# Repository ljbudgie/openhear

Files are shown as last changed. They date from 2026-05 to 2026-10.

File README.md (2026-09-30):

<p align="center">
  OpenHear hero
</p>

# OpenHear

**First time here?** Start at <a href="START_HERE.md">START_HERE.md</a> — phone, audiogram, ten minutes. You do not need GitHub after that.

### Your senses. Your data. Your world.



**Built on the Burgess Principle** — see [docs/BURGESS_PRINCIPLE.md](docs/BURGESS_PRINCIPLE.md).
→ <a href="docs/index.md">Full documentation index</a>

> **⚠️ EXPERIMENTAL — NOT A MEDICAL DEVICE**
> OpenHear is a research platform and public build log, not a certified hearing aid.
> Start at low volume, validate every configuration on your own hardware, and do
> not treat any module in this repository as a substitute for clinical care.

OpenHear is a human sensory sovereignty platform — not a hearing aid, not a wellness device, not a consumer gadget. It is an open-source sovereign audio pipeline, haptic environment engine, therapeutic delivery layer, and future aids-free sensory system.

**North star: human sensory sovereignty.** The user decides what they hear, when they hear it, how they hear it, and what their acoustic environment does to their body and mind. The long-term configuration is still direct: no hearing aid, no behind-the-ear receiver, no bone conduction implant, no ear canal device of any kind. The wristband IS the hearing system. See **[Vision — Aids-Free Hearing](#openhear-vision-2--aids-free-hearing-the-wristband-is-the-hearing-system)** below, the full eight-pillar platform architecture in [`docs/HUMAN_SENSORY_SOVEREIGNTY_ARCHITECTURE.md`](docs/HUMAN_SENSORY_SOVEREIGNTY_ARCHITECTURE.md), and the aids-free subsystem document in [`docs/AIDS_FREE_ARCHITECTURE.md`](docs/AIDS_FREE_ARCHITECTURE.md).

> *The hearing aid industry charges £3,000–£8,000 for hardware, then locks you out of it.*
> *Your audiogram is a measurement of your body. It belongs to you.*
> *OpenHear gives it back.*

---

## Contents

- <a href="START_HERE.md">Start here</a>
- [Why OpenHear in 2026](#why-openhear-in-2026)
- [What this is](#what-this-is)
- [The Burgess Principle](#the-burgess-principle)
- [The problem](#the-problem)
- [What OpenHear does](#what-openhear-does)
- [OpenHear Wristband — Active Environmental Intelligence](#openhear-wristband--active-environmental-intelligence)
- [OpenHear Vision — The Wristband as the Hearing System](#openhear-vision--the-wristband-as-the-hearing-system)
- [OpenHear Vision 2 — Aids-Free Hearing](#openhear-vision-2--aids-free-hearing-the-wristband-is-the-hearing-system)
- [Getting started — three paths](#getting-started--three-paths)
- [Roadmap](#roadmap)
- [Nine pillars](#openhear-expansion--nine-pillars)
- [Sovereign philosophy](#sovereign-philosophy--enforced-at-every-layer)
- [Contributing](#contributing)
- [Legal](#legal)
- [Author](#author)

---

## Why OpenHear in 2026

Commercial aids from Phonak, Signia, and Starkey still ship with proprietary AI that mangles your own voice, whistles during hugs, and dies in sweat. Replacements cost £3,000–£8,000 and lock you into manufacturer fitting software. OpenHear is the sovereign alternative: an open-source DSP pipeline with adaptive feedback cancellation, own-voice bypass, and sweat-proof 3D-printed ITE shells you manufacture at home. Every algorithm is inspectable. Every parameter is yours. No cloud. No subscription. No lock-in. Licensed under Apache 2.0 with a Sovereign Use Addendum (see [`LICENSE`](LICENSE)).

---

## What this is

OpenHear is an open-source human sensory sovereignty platform for people who are tired of factory AI, clinic gatekeeping, and environmental noise making decisions about their own senses without their consent.

It already works with aids you own and hardware you have. It is being extended into a wrist-native sensory system, a therapeutic haptic platform, a selective-hearing engine, and an acoustic privacy layer. It does not require an audiologist appointment to change a setting.

OpenHear is now both a software pipeline and a hardware concept. The pipeline gives you control over how your aids process sound. The hardware — the OpenHear Wristband (in development) — extends that control outwards into the environment itself, scanning for sounds your aids may not pick up and translating them into haptic awareness on the wrist. Software and hardware are unified by a single principle: the hearing aid user should have full sovereignty over how they perceive their acoustic environment.

OpenHear has nine pillars:

1. The OpenHear Wristband — active environmental intelligence
2. Aids-free architecture — the wristband as the complete hearing system
3. Peak hearing for all users
4. Selective acoustic sovereignty
5. Therapeutic frequency delivery
6. Native iOS and Android integration
7. Emotional and cognitive acoustic intelligence
8. Social acoustic layer
9. Beyond biological hearing

### New north-star documents

- Full architecture — [`docs/HUMAN_SENSORY_SOVEREIGNTY_ARCHITECTURE.md`](docs/HUMAN_SENSORY_SOVEREIGNTY_ARCHITECTURE.md)
- Aids-free subsystem architecture — [`docs/AIDS_FREE_ARCHITECTURE.md`](docs/AIDS_FREE_ARCHITECTURE.md)
- Research roadmap — [`docs/RESEARCH_ROADMAP.md`](docs/RESEARCH_ROADMAP.md)
- Immediate engagement list — [`docs/PRIOR_ART.md`](docs/PRIOR_ART.md)
- Go-to-market, mission, and showcase applications — [`docs/GO_TO_MARKET.md`](docs/GO_TO_MARKET.md)
- Funding and partnerships — [`docs/FUNDING_AND_PARTNERSHIPS.md`](docs/FUNDING_AND_PARTNERSHIPS.md)
- Regeneration vision and roadmap — [`REGEN_VISION.md`](REGEN_VISION.md)
- Superior-hearing roadmap (functionally exceed natural hearing) — [`SUPERIOR_HEARING_ROADMAP.md`](SUPERIOR_HEARING_ROADMAP.md)

### Mission

OpenHear gives people control over their own senses. It lets you choose what you hear, what you ignore, what your body learns from sound, and how your environment reaches you, whether you are deaf, hard of hearing, hearing, tired, stressed, training, sleeping, working, or simply wanting peace.

**Tested on:**
- Phonak Naída M70-SP (Marvel platform)
- Signia Insio 7AX (Augmented Xperience platform)

**Required hardware:**

Path 1 does not need this hardware. See START_HERE.md. Noahlink is only Path 2 (people who already own compatible aids and want to read their own fitting).

- Noahlink Wireless 2 (~£80 on eBay)
- Windows laptop (for fitting software)
- iPhone or Android (for streaming)
- OpenHear Wristband *(in development)* — continuous-wear haptic frequency scanner, pairs over Bluetooth with the rest of the pipeline. See the OpenHear Wristband section below.

---

## The Burgess Principle

The Burgess Principle is the ethical and architectural root from which OpenHear grows. It is a framework, authored by Lewis James Burgess, for sovereign handling of clinical audiology data — audiograms, fittings, MPO calculations — so that a patient, a clinician, and a regulator can each hold an independent, verifiable, offline record of what was committed to and by whom, without depending on the cooperation of any vendor.

It rests on five commitments, enforced in this repository (see `advocacy/gate.py`, `advocacy/adapters.py`, and `NOTICE`):

1. **Sovereign facts belong to the person they describe.** The audiogram and fitting profile are facts about a human body and are never transmitted, bundled, or shared without that person's explicit, informed consent.
2. **Every clinical commitment is cryptographically verifiable.** A SHA-256 commitment over a canonical serialisation of the facts is the only value intended to leave the device, and any party holding the bundle can verify it offline with no vendor involvement.
3. **Trust is binary: `SOVEREIGN` or `NULL`.** A real human personally reviewing the specific facts and signing a receipt produces `SOVEREIGN`; pure automation, blanket policy, an invalid signature, tampering, or a refusal to engage produces `NULL`. There is no third state.
4. **Raw audio is not a clinical fact.** Any attempt to commit `bytes`, `bytearray`, `memoryview`, or a NumPy `ndarray` into a facts payload raises `RawAudioRejectedError` before a commitment is produced.
5. **Schema ownership is singular.** The `openhear-advocacy-v1` schema family is owned by this repository; integrators do not fork, re-version, or extend it.

The advocacy layer in this repository is the reference implementation of these commitments. The next layer — **Iris**, an AI companion built within the Burgess Principle — will provide a higher-level advocacy workflow post-1.0.0. Iris will import OpenHear; OpenHear will not import Iris. An integration that satisfies the five commitments today will be compatible with Iris automatically.

The full statement of the principle, the integrator contract, and the runnable reference integration are in [`docs/BURGESS_PRINCIPLE.md`](docs/BURGESS_PRINCIPLE.md), [`docs/ADVOCACY_INTEGRATION.md`](docs/ADVOCACY_INTEGRATION.md), [`docs/INTEGRATORS.md`](docs/INTEGRATORS.md), and [`examples/reference_integration.py`](examples/reference_integration.py).

---

## The problem

Modern hearing aids are extraordinary pieces of engineering. They are also, deliberately, black boxes.

When you buy a Phonak or Signia aid, you get a device that:
- Constantly reclassifies your acoustic environment without telling you
- Applies compression, noise reduction, and beamforming algorithms you cannot inspect
- Stores your audiogram and fitting profile in a proprietary format you cannot read
- Requires a registered audiologist and £200+/hr of fitting time to adjust a single parameter
- Reverts to factory defaults if the fitting software version doesn't match

This is not a safety requirement. It is a business model.

The audiogram stored in your hearing aids is a biometric measurement of your nervous system. The fitting profile is a record of how your brain processes sound. You generated that data. You wore the sensors. You sat in the booth.

It is yours.

---

## What OpenHear does
```
World → Microphone → Custom DSP Engine → Bluetooth Stream → Your Aids → Your Ears
```

**Core module** — reads your existing fitting data out of your aids via Noahlink Wireless. Exposes it as plain JSON. No proprietary format, no locked PDF.

**DSP module** — real-time Python audio pipeline. You control the compression curve, the noise floor, the beamforming angle, the voice frequency emphasis. Tuned to your audiogram, not a population average.

**Stream module** — sends processed audio directly to your aids over Bluetooth. No extra hardware. Works on iPhone and Android.

**Audiogram module** — reads, visualises, and exports your hearing thresholds in open formats. The data your audiologist has been keeping in a system you can't access.

**Learn module** *(Phase 6)* — a local preference engine that adjusts to your own corrections over time. Listener A/B choices are captured by [`learn/preferences.py`](learn/preferences.py), folded into deterministic config suggestions by [`learn/engine.py`](learn/engine.py), and recalled per environment via the saved profiles in [`learn/profiles.py`](learn/profiles.py). Your hearing profile improves every day, not once every two years.

---

## OpenHear Wristband — Active Environmental Intelligence

The pipeline above improves the sound that already reaches your aids. The wristband does something different: it scans the environment in parallel, on the wrist, and tells you about sounds your aids never delivered — or sounds you weren't oriented toward.

It is a continuous-wear device designed to work *alongside* hearing aids, not replace them. Passive amplification becomes active environmental intelligence.

```
World → Wrist Microphone Array → On-device AI Classifier → Haptic Motor Array → Your Wrist
                                          ↕
                                     Bluetooth
                                          ↕
                                Aids · Phone · Pipeline
```

**Edge AI sound classification** — low-latency on-device inference identifies environmental sounds in real time. Nothing is sent to a cloud. Your environment is your data and it stays on the wrist. The same sovereignty principle that governs your audiogram governs every sample the wristband hears.

**Multi-motor haptic feedback** — an array of small motors arranged around the wrist creates a spatial sound field through haptic patterns. Different sound classes, directions, and frequency bands have distinct haptic signatures. You build a physical sense of your acoustic surroundings without relying solely on what your aids decide to amplify.

**Directional awareness through haptic mapping** — the wristband communicates not just *what* a sound is but *where* it is coming from. Motor positions map to compass points around the wrist, so a siren behind you, a voice to your left, and a doorbell in front feel distinctly different. This is spatial awareness for sounds the aids may not be picking up or that you simply aren't oriented toward.

**Bluetooth connectivity** — pairs with hearing aids, smartphones, and smart home systems. Speaks the same protocols as the rest of the OpenHear pipeline so the wristband, the aids, and the DSP module act as one unified system rather than three separate devices.

**Personalised AI models** — the classifier adapts to the user's specific environment over time. A user in a barbershop has different priority sounds to a user in an office; the model learns the difference and adjusts haptic responses accordingly, with no manual configuration. Adaptation happens locally on the device.

**Proactive frequency-specific scanning** — instead of reacting after a sound has occurred, the wristband actively scans the frequency spectrum and alerts you to sounds approaching your detection threshold *before* they become relevant. Environmental sonar, not environmental amplification.

### How it relates to existing devices

The collaboration enquiry that prompted this work came from Sharp Hearing, a UK audiology clinic that already features the [Neosensory Buzz](https://neosensory.com/) on their site — a basic haptic wristband that converts sound into vibration patterns. The OpenHear Wristband goes significantly further:

| Capability | Neosensory Buzz | OpenHear Wristband |
|---|---|---|
| Sound → vibration | ✓ | ✓ |
| On-device AI sound classification | — | ✓ |
| Directional haptic mapping (compass points on the wrist) | — | ✓ |
| Proactive frequency-specific scanning | — | ✓ |
| Personalised models that adapt to your environment | — | ✓ |
| Pairs into a sovereign open-source DSP pipeline | — | ✓ |
| Local-only — no cloud, no telemetry | partial | ✓ |

### Why this fits OpenHear

The developer wears Phonak Naída and Signia aids. The gap the wristband fills is one lived every day: aids amplify what reaches the microphones in front of your ears, in the direction you happen to be facing, within the frequency response the manufacturer chose. Everything outside that envelope is silence. The wristband closes that gap on the wrist, under the user's control, with the same data-sovereignty guarantees as the rest of the project.

---

## OpenHear Vision — The Wristband as the Hearing System

The wristband section above describes a companion device. This section describes where the architecture is going.

The long-term vision is direct: the wristband stops being a companion and becomes the hearing system. It captures the environment, classifies it, processes it against your audiogram, and transmits a finished audio signal to a minimal receiver worn at the ear. The £3,000–£8,000 behind-the-ear black box — with its proprietary firmware, locked fitting software, and audiologist-gated parameters — is no longer required. It is replaced by a piece of jewellery on the wrist and a passive driver at the ear.

### The architecture — three layers, one user

```
World → Wrist Mic Array + Hearing NPU → Wireless Link → Bone Conduction Receiver / Open-Fit Earbud → Cochlea
        [capture + classify + process]   [low-latency]   [deliver only]
```

**Layer 1 — Wrist (sensor and processor).** The wristband carries the microphone array, the hearing-specific neural processing unit, the audiogram, and the DSP pipeline. All of the intelligence of the system lives here, on the user's wrist, where it can be charged, updated, inspected, and replaced independently of anything worn at the ear.

**Layer 2 — Wireless transmission.** A low-latency link between the wrist and the ear-worn receiver. Sub-5ms end-to-end is the target. Standard, open, and inspectable — no proprietary radio that locks the receiver to a single vendor.

**Layer 3 — Ear (delivery only).** A minimal behind-the-ear bone conduction receiver, or an open-fit earbud, whose only job is to convert the finished signal into vibration or sound. No microphones. No classifier. No DSP. No firmware that does anything other than receive and drive a transducer. When it breaks, you replace a £30 part, not a £6,000 one.

### A hearing-specific NPU — designed for this and only this

The processor on the wrist is not a general-purpose AI chip with a hearing application bolted on top. It is a neural processing unit designed from first principles for one task: real-time, personalised hearing.

- **Sub-5ms end-to-end latency** — capture to ear. Anything slower is felt as delay during conversation.
- **Personalised audiogram-based DSP** — compression curves, frequency shaping, and feedback cancellation derived from *your* thresholds, not a population fit.
- **On-device classification and beamforming** — environmental scene analysis and spatial steering run locally, at the same latency budget as the DSP itself.
- **Performance targets that exceed current hearing aid SoCs** — at a fraction of the silicon cost, because the chip does one job extremely well rather than every job adequately.

A general-purpose chip repurposed for hearing will always lose to a chip that was drawn for hearing. We intend to draw the chip.

### Sovereignty extended to hardware

OpenHear already gives the user sovereignty over their audiogram, their fitting data, and the DSP algorithms that act on them. The wristband-as-hearing-system extends that sovereignty down to the silicon and out to every device worn on the body.

- **No proprietary firmware** at any layer of the stack — wrist, link, or receiver.
- **No locked fitting software.** The audiogram lives on the wrist as plain JSON. Adjusting a parameter means editing a value, not booking an appointment.
- **No audiologist gatekeeping.** Audiologists are welcome as collaborators and clinicians; they are not required as a key to your own hearing.
- **No vendor lock between layers.** The receiver at the ear is interchangeable. The wristband is interchangeable. The link is an open standard. The user owns every layer.

The hearing aid industry's business model depends on the user not being able to see inside the device. This architecture is the device with the lid removed.

### Regulatory pathway

The system enters the world as a **companion device** — running alongside existing hearing aids, augmenting them, doing nothing the aids themselves do. This is the position the current OpenHear pipeline and wristband already occupy and it requires no clinical claim to be made.

The standalone configuration — wristband plus bone conduction receiver, replacing the hearing aid entirely — is the longer pathway. The regulatory target for the standalone device in the United Kingdom is **UK MDR 2002 Class IIa**, the same classification carried by conventional air-conduction hearing aids. Clinical evidence accumulates first; the claim follows.

### Collaboration

Open source hardware and open source software, end to end. Schematics, RTL, firmware, DSP, and fitting tools all under permissive licenses. Specifically invited:

- **Audiologists** — clinical input on fitting protocols, validation, and the standalone regulatory pathway.
- **Chip designers** — architects and RTL engineers interested in a hearing-specific NPU built from first principles.
- **DSP engineers** — compression, beamforming, feedback cancellation, and own-voice detection at sub-5ms latency budgets.
- **Hearing aid users** — the people the system exists for. Lived experience is a design input, not a marketing line.

### Industry & Institutional Engagement

**Industry engagement (active, July–August 2026)**

Commercial integration conversations are active with multiple wellness technology and assistive device companies. The discussions cover acoustic environment classification, haptic rendering, and the governance wrapper.

The commercial model is COSS (Commercial Open Source Software): the open core (Apache 2.0) is permanently free; the governance layer (UK Certification Mark UK00004343685) is licensed commercially per device at scale. A formal term sheet for a two-phase integration partnership — Phase 1 technical evaluation, Phase 2 paid integration pilot — has been prepared and is in circulation.

Sharp Hearing (US audiology clinic) is recorded as the first formal industry contact, 20 April 2026.

**Institutional partnerships (active)**

- **Health Innovation North East and North Cumbria (HI NENC)**, funded by the UK Office of Life Sciences — Innovation Pathway ref 1643. A market analyst is conducting competitive landscape research across seven sections: competitor analysis, NHS landscape, regulatory pathway, patent/prior art, market sizing, pricing, and evidence base.
- **RNID (Royal National Institute for Deaf People)** — confirmed participant recruitment from the Research Panel (~1,600 members, ~1,100 hearing aid users) launching 12 August 2026. Innovation Seed Fund application planned November 2026.
- **UK Information Commissioner's Office** — IC-501417-W5W9: the ICO found Sonova/Phonak's response to a Subject Access Request regarding AutoSense OS algorithmic accountability inadequate (outcome letter 31 July 2026) and is writing to Sonova directly.
- **MHRA** — CEC 253215: medical device safety concern regarding AutoSense OS automated clinical decision-making; FOI2026/00527 internal review requested regarding DSAR reclassification and substantive regulatory questions.

**Regulatory and academic record**

- UK Certification Mark UK00004343685 accepted 21 July 2026, published in Trade Marks Journal 24 July 2026, opposition period to 24 September 2026.
- 7 papers publicly distributed on SSRN (author page: per\_id=11571908); lead paper: The Burgess Test v2.1 (SSRN 6759778).
- 100 classified findings across 12 sectors: 78 NULL, 8 SOVEREIGN, 10 AMBIGUOUS, 4 confirmed resolutions.
- First judicial validation: TPT DK00003-2605 ALLOWED, 14 June 2026.

**Accessibility profiles (v1.4.0+)**

Optional, user-declared accessibility profiles are shipped for cerebral palsy, autism, and sensory-processing needs. In the live wristband path they damp non-safety haptics, configure a firmware-enforced gradual onset, raise the confidence gate, and widen alert spacing; cerebral palsy also supplies hold-to-confirm and dysarthria-tolerant voice defaults. Alarm delivery remains subject to its perceptibility floor. Nothing is detected, inferred, stored, or transmitted. See [`accessibility/README.md`](accessibility/README.md).

---

## OpenHear Vision 2 — Aids-Free Hearing: the wristband IS the hearing system

The previous section described removing the £3,000–£8,000 behind-the-ear processor and keeping only a minimal ear-worn receiver. This section goes one further. **It removes the receiver too.**

There is no hearing aid in this system.
There is no behind-the-ear receiver.
There is no bone conduction implant.
There is no ear canal device of any kind.

There is a wristband, a personal model, an audiogram, and a brain trained to read them. The user owns all four.

The full eight-pillar platform architecture is in [`docs/HUMAN_SENSORY_SOVEREIGNTY_ARCHITECTURE.md`](docs/HUMAN_SENSORY_SOVEREIGNTY_ARCHITECTURE.md). The aids-free subsystem architecture is in [`docs/AIDS_FREE_ARCHITECTURE.md`](docs/AIDS_FREE_ARCHITECTURE.md). The 15 most critical open research questions are in [`docs/RESEARCH_ROADMAP.md`](docs/RESEARCH_ROADMAP.md). The immediate engagement list is in [`docs/PRIOR_ART.md`](docs/PRIOR_ART.md). The audience positioning, mission, and showcase applications are in [`docs/GO_TO_MARKET.md`](docs/GO_TO_MARKET.md). The funding and partnership strategy is in [`docs/FUNDING_AND_PARTNERSHIPS.md`](docs/FUNDING_AND_PARTNERSHIPS.md). What follows is the short version.

### Mechanism of action — sensory substitution, not amplification

OpenHear's standalone configuration is not a hearing aid by mechanism. It is a **somatosensory hearing substitution device**. Sound is captured at the wrist, classified by edge AI, weighted against the user's audiogram, and rendered as a high-resolution multi-frequency haptic field on the skin. The brain — through documented neuroplasticity, going back to Bach-y-Rita's 1969 tactile-vision substitution work — learns to read that field as auditory information.

This is the same class of device as the Neosensory Buzz, but with an order of magnitude more channels, true frequency-rich spatial encoding, audiogram-weighted band synthesis, and an open silicon and open RTL stack. It is not a hearing aid. It does not claim to restore cochlear function. It substitutes for it.

### Skin as the transducer

The volar wrist carries Pacinian, Meissner, Merkel and Ruffini mechanoreceptors covering roughly 5 Hz – 1 kHz of perceivable mechanical drive. Audio above this band is *encoded* — into motor position, drive pattern, and temporal structure across the array — not transmitted as raw vibration. Target actuator pitch is 8–12 mm, deliberately tighter than two-point discrimination, exploiting funnelling and apparent-motion illusions to produce a perceived spatial resolution finer than the physical receptor field.

- **Minimum viable**: 24 actuators in a single ring (Neosensory-class density).
- **Target v1**: 64 actuators in a 4-ring × 16-column lattice covering the wrist.
- **Aspirational v2**: 128 actuators extending up the forearm, enabling a 2D haptic "screen".

### Neural adaptation — open protocol, user-owned data

Adaptation is the design target, not raw signal fidelity. The training pipeline is published as a five-phase open protocol — calibration, phoneme sandbox, words and environment, open conversation, spatial and extended-spectrum — running on a cross-platform companion app. All data lives on the user's device as plain Parquet. There is no cloud account.

```
Phase 0  Calibration         (day 0,    ~90 min)   — perceptual mapping, motor thresholds, audiogram import
Phase 1  Phoneme sandbox     (week 1–2, 30 min/d)  — closed-set phoneme → haptic pattern drills
Phase 2  Word & environment  (week 3–6, 30 min/d)  — common words, alarms, name detection, traffic
Phase 3  Open conversation   (week 7+,  passive)   — continuous wear; periodic active-recall checks
Phase 4  Spatial & extended  (month 3+)            — direction, elevation, ultrasonic/infrasonic bands
```

Phase 2 has a local-only scaffold for word, name, and environment training:

```bash
python -m stream.phase2_training list
python -m stream.phase2_training run --target word_water --scores word_water=0.92 --progress /tmp/openhear-phase2-progress.json
python -m stream.phase2_training summary --progress /tmp/openhear-phase2-progress.json
```

The Phase 2 progress file stores only target ids, classifier labels, scores,
timing, and outcomes. It does not store raw audio or speaker identity.

Phase 3 has a local-only scaffold for open conversation telemetry:

```bash
python -m stream.phase3_open_conversation list-prompts
python -m stream.phase3_open_conversation passive   --sound-class voice --source-label Speech --confidence 0.9   --intensity 128 --progress /tmp/openhear-phase3-progress.json
python -m stream.phase3_open_conversation summary   --progress /tmp/openhear-phase3-progress.json
```

The Phase 3 progress file stores only derived metadata for passive wear and
active-recall checks. It does not store raw audio, waveforms, speaker identity,
or cloud identifiers, and it is experimental telemetry rather than clinical
evidence.

Phase 4 adds a local-only scaffold for spatial and extended-band training:

```bash
python -m stream.phase4_spatial_extended list-tasks
python -m stream.phase4_spatial_extended spatial --task localise_left --predicted-azimuth -80 --confidence 0.85 --user-response answered --progress /tmp/openhear-phase4-progress.json
python -m stream.phase4_spatial_extended extended --task band_ultrasonic --predicted-band ultrasonic --user-response ultrasonic --progress /tmp/openhear-phase4-progress.json
python -m stream.phase4_spatial_extended summary --progress /tmp/openhear-phase4-progress.json
```

The Phase 4 progress file stores only derived localisation, extended-band,
timing, environment, rating, and outcome metadata. It does not store raw audio,
waveforms, location traces, biometric identifiers, cloud identifiers, or
clinical claims.

### Phase 5 — Sovereign Device bundle

Phase 5 is the local, one-click bridge from an audiogram to a self-contained
device build. It generates firmware plus a sovereign build manifest from a
`openhear-audiogram-v1` JSON file, with no network dependency and no raw audio:

```bash
python -m hardware.sovereign_device.pipeline AUDIOGRAM.json ./build --ear right
```

The manifest records firmware, audiogram, and component-database hashes,
safety requirements, regulatory status, and cost-target status without
embedding the underlying audiogram thresholds. Full plan and exit criteria
are in [`docs/PHASE5_SOVEREIGN_DEVICE.md`](docs/PHASE5_SOVEREIGN_DEVICE.md).

### A Hearing NPU, designed from first principles

A general-purpose mobile SoC running PyTorch Mobile cannot meet the latency or power budget. The Hearing NPU is designed for *one* job: continuous, personalised, low-latency hearing-as-haptics.

| Stage | Latency budget |
|---|---|
| Mic capture + ADC | 0.3 ms |
| Front-end DSP (beamform, AEC, VAD) | 0.7 ms |
| Bark-band analysis (FFT/filterbank)| 0.5 ms |
| Audiogram weighting | 0.1 ms |
| Classification + scene tag | 1.5 ms |
| Haptic render (mapping + envelope) | 0.6 ms |
| Motor driver chain | 0.8 ms |
| Mechanical rise time (LRA/piezo) | 0.5 ms |
| **End-to-end target** | **≤ 5 ms**|

- **ISA**: RISC-V RV32IMC + RVV 1.0 (open ISA, open implementations).
- **Accelerator**: 8 × INT8/INT4 MAC tiles at ~2 TOPS, hardwired bark filterbank, single-cycle audiogram lookup, deterministic haptic scheduler.
- **SRAM-only data path**: 4 MB on-die, no DRAM. The model lives entirely on chip; this is the architectural reason ≤ 5 ms is achievable.
- **Power envelope**: 80–120 mW continuous, < 5 mW idle.
- **Open RTL** under CERN-OHL-S. No proprietary IP in the data path.

Until tape-out, the staged hardware path is: v0 on Raspberry Pi CM4 + Hailo-8L (~30 ms latency, sufficient for adaptation studies) → v0.5 on a RISC-V SBC + Coral Edge TPU (~15 ms) → v1 FPGA validation on Lattice ECP5 with the open RTL (~5 ms) → v1 ASIC at 22 nm FD-SOI.

### Beyond hearing — capabilities a hearing aid cannot have

Once sound is decoupled from the ear and rendered as multi-channel haptics, the system trivially extends past biological limits.

- **Infrasonic** (1–20 Hz) — earthquake precursors, large-vehicle approach, HVAC faults.
- **Ultrasonic** (20–96 kHz with appropriate MEMS) — bat activity, leak detection, dog whistles.
- **Full-sphere spatial awareness** — azimuth via beamformer, elevation via ring index, distance via envelope decay. Above and below the wearer, which biological hearing handles poorly.
- **Multi-source separation** — render two simultaneous speakers to two distinct regions of the wrist, allowing the wearer to "listen" to both in parallel.
- **Persistent acoustic memory** — last 30 s ring buffer, replayable on demand to the haptic field.
- **Contextual silencing** — known irritant classes attenuated by the classifier, not by global compression.

Biological hearing is a 20 Hz – 20 kHz omnidirectional pressure sensor with poor elevation discrimination and no scene understanding. OpenHear, on the wrist, is none of those things and all of the things they cannot be. The aids-free configuration is **superior, not equivalent**.

### Sovereignty enforced at the technical layer

The user owns:

1. **Audiogram** — `~/.openhear/audiogram.json`
2. **Haptic preference profile** — `~/.openhear/profile.json`
3. **Personal adaptation model** — `~/.openhear/model.bin` (LoRA delta over the open base)
4. **Adaptation telemetry** — `~/.openhear/training/*.parquet`
5. **Any captured audio** — opt-in only, encrypted with a key the user holds.

Enforcement is not a policy promise; it is built in:

- The NPU has no IP stack. There is no network egress in the hearing data path.
- Firmware is signed, but the signing key is the user's. A user can sign and load their own firmware. (This is the inverse of the hearing aid industry's lock-down.)
- Plain-file formats end to end — JSON, Parquet, ONNX, WAV. No proprietary container.
- Every parameter an audiologist would set in proprietary fitting software is a writable field in `profile.json`. Audiologists are welcome collaborators; they are not a key.

### Regulatory pathway — sensory substitution, not hearing aid

Regulatory classification follows mechanism, not indication. The aids-free OpenHear has the same mechanism as Neosensory Buzz and BrainPort, both of which are cleared as sensory substitution devices, not hearing aids.

| Jurisdiction | Likely classification | Comparator predicate |
|---|---|---|
| **UK (MHRA)** | UK MDR 2002 — Class I (initial), Class IIa if claims tighten | Neosensory Buzz |
| **US (FDA)**  | 510(k) Class II, sensory substitution | Neosensory Buzz, BrainPort Vision Pro |
| **EU (MDR)**  | Class I or IIa under MDR 2017/745 | Same |

The fastest credible path: bench validation in months → single-user adaptation log (publicly, by the developer) → multi-user pilot (n≈20) in year 1 → controlled trial in year 2 → submission in year 3. Open data at every stage.

### Open hardware path

- Schematics: KiCad 8 wristband package planned for a future `hardware/wristband/` directory; not yet committed in this repo.
- RTL: Verilog/SystemVerilog Hearing NPU package planned for a future `hardware/npu/` directory; not yet committed in this repo.
- Mechanical: FreeCAD/OpenSCAD wristband CAD planned for a future `hardware/wristband/mech/` directory; not yet committed in this repo.
- BOM: globally-available distributors only; no single-source critical parts.
- Targeting OSHWA certification at v0 and a Hackaday Prize / Open Hardware Summit submission.

### Specifically invited

- **Mechanoreceptive psychophysicists** — for Q1 (information bandwidth of the wrist) and Q4 (calibration protocol) of the [research roadmap](docs/RESEARCH_ROADMAP.md).
- **Sensory-substitution neuroscientists** — for Q2 (adaptation timeline) and the cortical remap evidence base.
- **RISC-V RTL engineers** — for the Hearing NPU.
- **Embedded DSP engineers** — for the sub-5 ms front-end and haptic renderer.
- **UK / EU / US audiology clinicians** — for the multi-user pilot and the regulatory pre-submissions.
- **Deaf and hard-of-hearing wearers** — the people the system exists for. Lived experience is a design input, not a marketing line.

The longer this section gets, the closer the architecture is to leaving the page. The architecture document and roadmap are both in this repo. Read them; fork them; contradict them; submit a PR.

---

## The three pain points this solves

| Problem | Factory behaviour | OpenHear behaviour |
|---|---|---|
| Voices sound unnatural | AutoSense OS reclassifies constantly, smears transients | Linear mode + tunable WDRC compression |
| Constant unwanted adjustments | Environment AI fires every few seconds | You are the AI |
| Too much background noise | Fixed factory noise floor | Tunable beamforming, adjustable noise gate |

---

## Philosophical foundation

OpenHear is built on **the Burgess Principle** (summarised above and stated in full in [`docs/BURGESS_PRINCIPLE.md`](docs/BURGESS_PRINCIPLE.md)) — the position that data generated by or about your body belongs to you and not to the institution that measured it, and that any clinical commitment about your body must be independently verifiable, offline, by anyone holding the bundle.

The advocacy layer in this repository is the reference implementation of that principle. The principle in turn sits within a wider body of work on data sovereignty by the same author, including [the legal framing repository](https://github.com/ljbudgie/Burgessprinciple) on void ab initio against bulk-processed warrants and tainted data records.

OpenHear applies the principle directly to audiological data:

- Your audiogram was generated by measuring *your* auditory nerve response. It is yours.
- Your fitting profile was created by adjusting parameters until *your* perception was satisfied. It is yours.
- The Noahlink Wireless is your key. The open standard is your right. The algorithms are yours to read, copy, modify, and improve.

See `SOVEREIGN_AUDIO.md` for the full framework.

---

## Getting started — three paths

### Path 1 — Quick start (phone + existing aids)
1. Install the experimental OpenHear Android scaffold from `/mobile/` — see [mobile README](mobile/README.md) for the current skeleton-only status
2. Load your audiogram JSON (export from your audiologist or create one using `audiogram/data/FORMAT.md`)
3. Pair your aids via Bluetooth Classic or ASHA
4. Tap ▶ once you have verified the current mobile build supports the stages you need on your device; the Android app is an active public prototype, not a finished clinical tool

### Path 2 — Desktop pipeline (Windows + Noahlink Wireless 2)
1. Set your aids to linear mode (kill the factory AI — see instructions below)
2. `pip install -e .` (editable install using the new `pyproject.toml`)
   or `pip install -r requirements.txt` for the legacy flow
3. `python -m core.read_fitting` — exports the current raw Noahlink payload to JSON; add `--session` to emit the new structured `FittingSession` format and `--verbose` for DEBUG logging
4. `python -m dsp.pipeline` — starts the real-time audio processor. Useful flags: `--bypass` for A/B, `--test-tone` when no mic is plugged in, `--latency` for per-block latency logs, `--metrics-csv metrics.csv` to record CPU / RMS / latency
5. Copy `examples/config.yaml` to `~/.openhear/config.yaml` and tune it (see `docs/TUNING_GUIDE.md`); `dsp/config.py` defaults still work as a fallback
6. Optional — exercise the aids-free training scaffolds with
   `python -m stream.phase2_training`,
   `python -m stream.phase3_open_conversation`, and
   `python -m stream.phase4_spatial_extended`; build a sovereign-device bundle
   with `python -m hardware.sovereign_device.pipeline AUDIOGRAM.json ./build`

### Path 2.5 — Wristband prototype (Windows + micro:bit v2)
1. Export or copy the patient's audiogram JSON
2. Flash the micro:bit with [`wristband/openhear_firmware.py`](wristband/openhear_firmware.py) using the Windows editor workflow in [`HARDWARE.md`](HARDWARE.md#firmware-flashing-windows)
3. Wire the two-motor transistor stage exactly as described in [`HARDWARE.md`](HARDWARE.md#exact-motor-driver-wiring-tested-values)
4. Install Python dependencies with `pip install -r requirements.txt`
5. For a dry packet check, run:
   - `python -m haptic_commander --audiogram PATIENT.json --sound-class alarm --dry-run`
6. For a BLE-only smoke test, run:
   - `python -m haptic_commander --audiogram PATIENT.json --sound-class alarm`
7. For live classification, add a local YAMNet `.tflite` model and use the bundled official label CSV:
   - `python -m stream.wristband_runtime --audiogram PATIENT.json --model yamnet.tflite --labels stream/data/yamnet_class_map.csv`
8. To validate the classifier without BLE, run:
   - `python -m yamnet_classifier --model yamnet.tflite --labels stream/data/yamnet_class_map.csv --limit 10`
9. If Windows BLE pairing or discovery fails, use the debugging checklist in [`HARDWARE.md`](HARDWARE.md#windows-ble-debugging-checklist) and the release notes in [`wristband/README.md`](wristband/README.md)

The wristband runtime currently supports:
- 7 sound classes (`voice`, `doorbell`, `alarm`, `dog`, `traffic`, `media`, `silence`)
- audiogram-weighted intensity scaling from either the current v1 format or the legacy OpenHear v0.1.0 JSON export
- BLE UART transport to a micro:bit advertising as `OpenHear`
- patient safety defaults that bias toward the **worst** ear when one intensity byte must represent both ears

The v1.0.0 clinic prototype keeps Noahlink extraction on a separate hardening
track: the wristband already accepts audiogram JSON, while direct parsing in
`core/read_fitting.py` and `audiogram/reader.py` still contains placeholder
frame parsing that needs real-device confirmation.

To keep a running development memory inside the repository, use:

```bash
python -m core.future_memory add --topic sharp-hearing --note "Prototype flashed and paired."
python -m core.future_memory latest --topic sharp-hearing
```

### Path 3 — Full sovereign build (phone + photogrammetry + resin printer)
1. Scan your ear using Polycam/Scaniverse photogrammetry (see [workflow](hardware/ite-shells/workflow.md))
2. Customise the parametric shell in OpenSCAD (see [parametric_shell.scad](hardware/ite-shells/parametric_shell.scad))
3. Print on Elegoo Saturn 4 / Anycubic (see [print settings](hardware/ite-shells/print_settings.md))
4. Apply nano-coating for sweat-proofing (see [sweatproof guide](hardware/ite-shells/sweatproof.md))
5. Assemble with OpenHear electronics, load the mobile app, and own your sound

### Kill the factory AI

Before using Path 2 or 3, set your aids to linear mode. This alone will transform your sound.

**Phonak Naída (Marvel/Paradise/Lumity):**
1. Install [Phonak Target](https://www.phonakpro.com/com/en/resources/software-and-firmware/phonak-target.html) on Windows
2. Connect Noahlink Wireless 2 via USB
3. Open fitting → Gain & MPO → set processing to Linear
4. Disable AutoSense OS scene classification
5. Save and close

**Signia Insio (AX platform):**
1. Install [Connexx](https://www.signiausa.com/professionals/software/) on Windows
2. Connect Noahlink Wireless 2 via USB
3. Open fitting → set to linear amplification
4. Disable Own Voice Processing auto-switching
5. Save and close

---

## Roadmap

- [x] Hardware identification and compatibility testing
- [x] Noahlink Wireless 2 bridge protocol research
- [x] `core/` — fitting data reader (JSON export)
- [x] `dsp/` — real-time Python pipeline (PyAudio + NumPy)
- [x] `stream/` — Bluetooth audio output module
- [x] `audiogram/` — threshold reader and visualiser
- [x] `hardware/ite-shells/` — parametric ITE shell design + sweat-proofing
- [x] `dsp/feedback_canceller` — adaptive feedback cancellation (LMS)
- [x] `dsp/own_voice_bypass` — own-voice detection and DSP bypass
- [x] `mobile/` — Android scaffold (Compose UI + Oboe/JNI audio engine skeleton)
- [ ] `mobile/` — production-ready Android DSP + hearing-aid streaming
- [x] `learn/` — on-device preference learning engine (Phase 6: `preferences.py` capture, deterministic `engine.py` config suggestions, per-environment `profiles.py`)
- [ ] `ui/` — desktop GUI (the OSCAR moment)
- [ ] iOS version of mobile app
- [ ] Community scan library
- [ ] tinyML Learn module v2

### Aids-free configuration (Vision 2)

- [x] Human sensory sovereignty platform architecture — [`docs/HUMAN_SENSORY_SOVEREIGNTY_ARCHITECTURE.md`](docs/HUMAN_SENSORY_SOVEREIGNTY_ARCHITECTURE.md)
- [x] Architecture document — [`docs/AIDS_FREE_ARCHITECTURE.md`](docs/AIDS_FREE_ARCHITECTURE.md)
- [x] Research roadmap — [`docs/RESEARCH_ROADMAP.md`](docs/RESEARCH_ROADMAP.md)
- [x] Prior art and engagement list — [`docs/PRIOR_ART.md`](docs/PRIOR_ART.md)
- [x] Go-to-market, mission, and showcase applications — [`docs/GO_TO_MARKET.md`](docs/GO_TO_MARKET.md)
- [x] Funding and partnership strategy — [`docs/FUNDING_AND_PARTNERSHIPS.md`](docs/FUNDING_AND_PARTNERSHIPS.md)
- [ ] `hardware/wristband/` — KiCad schematics, mechanical CAD, BOM (planned; directory not yet committed)
- [x] `hardware/wristband/` — micro:bit v2 prototype firmware and wiring guide
- [ ] `hardware/npu/` — open RTL for the Hearing NPU (RISC-V + custom accelerator, CERN-OHL-S; planned, directory not yet committed)
- [ ] `firmware/npu/`, `firmware/mcu/` — bare-metal Rust runtime
- [ ] `dsp/haptic/` — frequency→position mapping, illusion library, audiogram weighting
- [ ] `models/` — base classifier, separator, and personal-LoRA scaffold
- [ ] `training/protocol/` — Phase 0–4 training app and metrics (Phases 2–4 currently scaffolded under `stream/phase{2,3,4}_*.py`; Phases 0–1 still pending)
- [ ] v0 prototype on Raspberry Pi CM4 + Hailo-8L + 24-LRA wrist sleeve
- [ ] v0.5 prototype on RISC-V SBC + 64-piezo lattice
- [ ] v1 FPGA validation on Lattice ECP5
- [ ] FDA Q-Sub and MHRA Innovation Office pre-submission
- [ ] Multi-user adaptation pilot (n≈20) with a UK academic audiology partner

## OpenHear expansion — nine pillars

The pipeline, hardware work, and roadmap above remain in force exactly as written. What follows is the expansion: OpenHear as a human sensory sovereignty platform spanning nine explicit pillars.

## Pillar 1 — The OpenHear Wristband: Active Environmental Intelligence

The OpenHear Wristband is a continuous-wear frequency scanner designed to work alongside existing hearing aids now and make them unnecessary later. It converts passive amplification into active environmental intelligence.

- **Edge AI sound classification** — low-latency on-device AI identifies and classifies environmental sounds in real time, entirely locally. No cloud. No telemetry. No data leaving the wrist.
- **Multi-motor haptic array** — an array of motors creates a spatial sound field through distinct haptic patterns. Different sounds, directions, and frequencies become different signatures on the skin.
- **Directional awareness through haptic mapping** — the wristband tells the user not just what a sound is but where it is coming from, using compass-point mapping around the wrist.
- **Bluetooth LE Audio connectivity** — the wristband pairs with existing hearing aids, smartphones, Apple Watch, and smart home systems, integrating directly with the OpenHear DSP pipeline.
- **Personalised adaptive AI models** — the classifier learns the user's actual environment over time. A barbershop, a stadium, a concert hall, a surgery, and a nursery do not sound the same and should not be treated the same.
- **Proactive frequency scanning** — the wristband actively scans the spectrum and warns about sounds approaching detection threshold before they become relevant. Environmental sonar, not environmental amplification.

Sharp Hearing (US audiology clinic, 20 April 2026) is the first formal industry contact recorded for this direction. As of July–August 2026, commercial integration conversations are active with multiple wellness technology and assistive device companies, and institutional partnerships are in place with HI NENC, RNID, the ICO, and MHRA. See the Industry & Institutional Engagement section above for the current state.

## Pillar 2 — Aids-Free Architecture: The Wristband as the Complete Hearing System

The wristband is not permanently a companion to hearing aids. It is the first step toward a full system in which no hearing aid, no behind-the-ear receiver, and no ear canal device of any kind is required.

- The wristband captures environmental sound via microphones, runs edge AI classification, and processes the full signal on-device.
- A dedicated **hearing-specific neural processing unit** is designed from first principles for this task, targeting sub-5 ms end-to-end latency from environmental sound capture to haptic output.
- **Somatosensory substitution** becomes the delivery path: the skin carries structured auditory information and the brain learns to read it.
- Where a minimal early receiver is useful, the system supports a coin-sized bone-conduction transducer behind the ear, driven wirelessly from the wristband, with no ear canal blockage and no clinic-gated fitting lock.
- The hardware stack is open from chip level upward: **RISC-V**, custom FPGA validation, and community-contributed hardware designs.
- The regulatory path starts as a companion device beside existing aids and builds toward standalone replacement as evidence accumulates, with the UK MDR 2002 Class IIa pathway in view for the standalone device.

## Pillar 3 — Peak Hearing for All Users

OpenHear is not only for people with hearing loss. It treats peak childhood hearing as the baseline reference and rejects progressive acoustic decline as an unchangeable fact of adult life.

- **Hearing users** get restoration and extension of sensitivity lost over time.
- **Deaf users** get full sensory access for the first time through open, trainable substitution pathways.
- **Children** get support for peak auditory development and earlier drift detection before conventional diagnosis.
- **Athletes and performers** get acoustic acuity beyond what biological hearing and training alone can deliver.

The training protocol, adaptation timelines, onboarding flows, and community training programmes are open source and user-owned.

## Pillar 4 — Selective Acoustic Sovereignty

OpenHear does not just help the user hear more. It gives the user complete control over what enters consciousness. The acoustic environment is no longer something that happens to the user; it is something the user configures.

**Required focus modes**

- **Crowd filter** — preserve coach, teammate, referee, or foreground conversation while the crowd drops away.
- **Concert mode** — keep the performance, attenuate chatter, bar noise, and venue distortion, and reconstruct the optimal listening position regardless of where the user is standing.
- **Deep focus** — maximise clarity for one voice or one task while reducing environmental load and tracking cognitive benefit through HRV correlation.
- **Situational awareness** — maximise environmental intelligence, classification, and spatial mapping for cyclists, runners, parents, and public-space safety.
- **Sleep mode** — attenuate traffic, neighbours, and irrelevant noise while preserving the user's child, their alarm, or a specific critical alert tone.
- **Performance mode** — profession-specific acoustic profiles for surgeons, pilots, musicians, athletes, dispatchers, and anyone whose work depends on hearing specific cues.
- **Privacy mode** — directional microphone nulling, acoustic fingerprint masking, and environmental sound signature anonymisation so the user controls not only what they hear but what the environment reveals about them.

The **Acoustic Profile Store** is an open community repository of acoustic profiles: forkable, shareable, reviewable, and governed like code rather than an app store.

## Pillar 5 — Therapeutic Frequency Delivery: 30 to 300 Hz

OpenHear uses the same wristband as a programmable therapeutic delivery surface across the 30-300 Hz range, either alongside hearing substitution or independently of it.

- **40 Hz gamma stimulation** — anchor protocol for cognitive and neural-entrainment research.
- **Whole-body vibration adjacency** — lower-frequency recovery and regulation patterns translated into a wrist-safe, continuous-wear format.
- **Skin and connective tissue stimulation** — 30-100 Hz protocols for collagen, elasticity, and dermal repair research.
- **Athletic recovery** — post-exercise delivery windows for muscle repair and inflammation management.
- **Personal evidence building** — HealthKit and Android Health Connect log HRV, sleep quality, activity, and skin conductance so the user builds their own evidence base locally.

Therapeutic scheduling integrates with Apple Watch and Wear OS sleep-stage detection so timing is phase-aware, measurable, and user-owned.

## Pillar 6 — iOS and Android Native Integration

Apple and Android devices are not a bolt-on companion. They are the first infrastructure layer for OpenHear's mobile runtime.

- **Apple stack** — Neural Engine, Core Haptics, Core Audio, HealthKit, Core Location, Maps, Spatial Audio, Apple Watch, ARKit, Shortcuts, and Automation.
- **Android stack** — TensorFlow Lite, NNAPI, Oboe, Health Connect, advanced haptic APIs, Google Maps Platform, Wear OS, and assistant integrations where the user wants them.
- **Location-triggered profile switching** — entering a barbershop, stadium, nursery, theatre, office, or concert hall automatically activates the right acoustic profile.
- **Open SDK** — third-party developers can build OpenHear-compatible applications without routing user data through a central company server.

All health data stays on-device and inside the user's own health record. There is no platform lock-in and no mandatory vendor cloud.

## Pillar 7 — Emotional and Cognitive Acoustic Intelligence

OpenHear learns how sound affects this specific user, not a statistical average of other people. Apple Watch and Android wearables provide the biometric substrate; OpenHear keeps the model local and the decisions explainable.

- Detect dropping HRV and automatically shift acoustic profile to attenuate stressors and optionally introduce therapeutic frequencies.
- Learn that crowd noise, transport hubs, or certain venues are physiologically stressful for this user and intervene before overload arrives.
- Distinguish positive arousal from negative arousal so a concert high is not treated like commuting stress.
- Keep all correlation data on-device in the user's HealthKit or Health Connect record plus local model storage the user can inspect, export, or delete.

## Pillar 8 — Social Acoustic Layer

OpenHear users should be able to share acoustic meaning, not just settings.

- **Shared acoustic presence** — two users in different places experience the same acoustic profile simultaneously.
- **Haptic communication** — a new non-verbal channel built from user-owned haptic vocabulary. A squeeze can mean “I am here.” A rhythm can mean “pay attention.” A burst can mean “I love this moment.”
- **Community acoustic mapping** — venues, transport hubs, parks, streets, and public spaces become annotatable for acoustic accessibility, safety, and therapeutic quality.
- **Accessibility ratings surfaced through maps** — contributed anonymously, verified by community consensus, and never dependent on uploading raw audio.

## Pillar 9 — Beyond Biological Hearing

With peak childhood hearing as the baseline, OpenHear moves into augmentation.

- **Ultrasonic detection** — 20 kHz to 100 kHz translated into haptic patterns for machinery signatures, structural monitoring, and signals no unaided human has ever perceived.
- **Infrasonic detection** — below 20 Hz for seismic activity, large-system resonance, infrasonic animal communication, and weather-adjacent environmental change.
- **360° plus spatial awareness** — horizontal, vertical, overhead, around-corner, and behind-wall cues rendered as trainable haptic information.
- **Predictive environmental awareness** — anomalies against the learned baseline of a place trigger distinct alerts.
- **Professional augmentation** — engineers hearing stress frequencies in a bridge, clinicians extending auscultation beyond biological limits, musicians hearing harmonic detail beyond the unaided ear.

## Sovereign Philosophy — Enforced at Every Layer

The Burgess Principle binary test applies to every OpenHear decision: does this feature treat the user as a sovereign individual with complete control over their own senses, or does it process them as a unit inside someone else's system. If the answer is the latter, it is redesigned until the answer is the former.

- No proprietary algorithms at any layer.
- No locked firmware.
- No platform gatekeeping.
- No company server receiving user data.
- The user's audiogram, haptic preference profile, acoustic focus modes, therapeutic schedule, trained AI model, neural adaptation data, biometric correlations, and health outcomes belong exclusively and irrevocably to them.
- The Acoustic Profile Store follows the same principles as the codebase: open, forkable, community-governed, and not controlled by a central authority.
- The open-source licence is part of the technical architecture. No future owner gets to close the sovereignty path.

### Burgess Principle extension point

The sovereign philosophy has an explicit API surface in `advocacy/`. It is a minimal, offline, dependency-free extension point that lets a companion advocacy tool (for example [Iris](https://github.com/ljbudgie/Iris), the reference Burgess Principle implementation) consume OpenHear records — audiograms, fitting profiles, MPO safety calculations — without OpenHear ever importing the companion or phoning home to it. The package produces SHA‑256 commitments over sovereign records, tags returning receipts as `SOVEREIGN` or `NULL`, and emits offline export bundles carrying both the OpenHear "experimental, not a medical device" disclaimer and an "advisory only, not legal advice" disclaimer. Raw environmental audio is refused at the adapter boundary by design. See [`docs/ADVOCACY_INTEGRATION.md`](docs/ADVOCACY_INTEGRATION.md) for the full contract. A full advocacy workflow (tribunal-ready bundles, draft challenge language, shared vault formats) is scoped for post-v1.0.0 work with Iris.

### For Industry Integrators

OpenHear's Sovereign Advocacy Layer is designed to be integrated into hearing device manufacturer software, audiology platforms, and AI clinical systems. If you have been granted permission by the author, start with <a href="docs/INTEGRATORS.md">docs/INTEGRATORS.md</a>.

### Advocacy quickstart

For a runnable, self-contained walkthrough of the full integration — happy path (SOVEREIGN bundle), tamper detection (NULL bundle), and the `RawAudioRejectedError` boundary — see [`examples/reference_integration.py`](examples/reference_integration.py). It imports only from `advocacy` and the Python standard library, and runs offline with no flags or configuration:

```bash
python examples/reference_integration.py
```

### Accessibility profiles — fitting the body, not just the ears

Every other tuning path here starts from an audiogram. That is only half the fit. If your muscle tone shifts through the day, if vibration can trigger a spasm or a startle, if an involuntary movement can press a control you never meant to press, or if your speech varies widely between repetitions, the "correct" audiogram-derived settings can still be the wrong settings for you.

`accessibility/` holds that second half as bounded, user-declared data. **Cerebral palsy**, **autism**, and **sensory processing** are equal opt-in starting points, not diagnoses. During a live wristband session, the selected profile dampens non-safety haptics, configures a firmware-enforced gradual onset, spaces alerts out, and rejects more low-confidence detections; cerebral palsy additionally supplies hold-to-confirm input defaults and dysarthria-tolerant voice scoring. Safety-critical alerts retain their perceptibility floor. Every value is overridable for the session, nothing is inferred or retained, and co-occurring conditions such as epilepsy are *screened for*, never assumed. See [`accessibility/README.md`](accessibility/README.md).

---

## Contributing

If you wear hearing aids and you're frustrated — this is your repo too.

If you're a DSP engineer who wants to build something that actually matters to real people — open an issue.

If you're an audiologist who believes your patients should own their own data — we especially want to hear from you.

Before you open an issue or a pull request, please read:

- [`CODE_OF_CONDUCT.md`](CODE_OF_CONDUCT.md) — Contributor Covenant 2.1, with
  project-specific additions covering ableist language and the privacy of
  audiometric data.
- [`SECURITY.md`](SECURITY.md) — private vulnerability disclosure process,
  including a dedicated path for hearing-safety reports. **Do not** file
  hearing-safety issues in the public tracker.
- [`CHANGELOG.md`](CHANGELOG.md) — running log of user-visible changes,
  following [Keep a Changelog](https://keepachangelog.com/en/1.1.0/). Add an
  entry under `[Unreleased]` as part of any user-visible PR.

The repository ships [issue templates](.github/ISSUE_TEMPLATE/) for bug
reports, feature requests, and hearing-aid compatibility reports, plus a
[pull request template](.github/PULL_REQUEST_TEMPLATE.md) and
[`CODEOWNERS`](.github/CODEOWNERS) for review routing. Dependency upgrades
land automatically via [`.github/dependabot.yml`](.github/dependabot.yml)
(`pip` and `github-actions`).

### Development & tooling

The repo is set up so that `make ci` reproduces what GitHub Actions runs.

```bash
make install-dev   # editable install + ruff, pytest-cov, build, pre-commit
make lint          # ruff check + ruff format --check
make format        # ruff format + ruff check --fix
make test          # pytest -q
make coverage      # pytest with coverage (term + xml)
make build         # python -m build  → sdist + wheel into ./dist
make ci            # lint + tests, same as the CI job
```

All tool configuration lives in [`pyproject.toml`](pyproject.toml) under
`[tool.ruff]`, `[tool.mypy]`, `[tool.coverage]`, and a consolidated
`[tool.pytest.ini_options]` section (the old `pytest.ini` has been removed;
test discovery and behaviour are unchanged). Editor defaults are pinned in
[`.editorconfig`](.editorconfig), and [`.pre-commit-config.yaml`](.pre-commit-config.yaml)
wires the same `ruff` checks into a `pre-commit install` hook so the
in-tree style stays consistent.

CI ([`.github/workflows/ci.yml`](.github/workflows/ci.yml)) runs lint,
the test suite with coverage, a packaging smoke test (`python -m build`
followed by a `pip install` of the resulting wheel), and a Windows job to
match the README's "Windows 11 primary target" claim. A separate
[CodeQL workflow](.github/workflows/codeql.yml) provides static security
analysis of the Python codebase.

Phase 6 adds local listener preference capture, deterministic adaptive config
suggestions, and per-environment saved profiles. A May 2026 coverage pass
confirms the Python suite exercises the core DSP, audiogram, advocacy,
wristband, stream, hardware safety, and Phase 5 sovereign-device paths with
branch coverage enabled. The lowest-coverage gaps found in that pass were the
live wristband runtime loop and micro:bit firmware main-loop/fallback branches;
both now have deterministic tests using local hardware stubs, so mobile-native
work can start from a stronger regression baseline without requiring BLE, audio
devices, or a micro:bit in CI.

A note on repository hygiene: `.gitignore` no longer blanket-ignores
`*.json`, `*.png`, and `*.pdf` at every depth. Build and output
directories are ignored explicitly, so new fixtures, schemas, and
documentation media will not be silently dropped from commits.

---

## Legal

OpenHear does not modify, reverse-engineer, or redistribute any proprietary firmware. It uses the Noahlink Wireless 2 and standard fitting software interfaces in the same way any hearing care professional would. It streams audio to hearing aids using standard Bluetooth audio profiles.

Your audiogram is yours. Your fitting data is yours. This software helps you access both.

Licensed under the Apache License, Version 2.0, with the OpenHear Sovereign Use
Addendum. See [`LICENSE`](LICENSE) and [`NOTICE`](NOTICE) for the full terms.

---

## Safety & Disclaimer

> **⚠️ EXPERIMENTAL PROJECT — NOT A MEDICAL DEVICE**
>
> OpenHear is an experimental open-source project. It has not been evaluated, approved, or cleared by any regulatory body (FDA, MHRA, CE/UKCA, or equivalent). It is not a medical device. Consult a qualified audiologist before making any changes to your hearing aid configuration. Use at your own risk.

---

## Author

**Lewis Burgess** — also the author of [The Burgess Principle](https://github.com/ljbudgie/Burgessprinciple).

Contact: <lewisjames@theburgessprinciple.com>

*Two repos. One argument. Your data belongs to you.*

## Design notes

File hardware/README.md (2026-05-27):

# hardware/ — From Audiogram to Wearable

This module bridges OpenHear's software pipeline to physical wearable hardware.

The goal: a fully open-source hearing aid. 3D printed shell. Commodity transducers. Open DSP. No proprietary firmware. No locked-down fitting software. No gatekeepers between you and your own hearing.

**Total build cost target: under £550 for a complete binaural (both ears) system.**

The hardware design prioritises **safety above all else**. Hardware MPO (Maximum Power Output) limiters are mandatory. They cap the sound level reaching your ear regardless of what the software does. This is non-negotiable. Read the [safety module](safety/README.md) before you build anything.

---

## Build Tiers

OpenHear hardware has three build tiers. Start wherever you are comfortable. Every tier produces a functional hearing device.

### Tier 1: Explorer (~£300)

**What it is:** A Tympan board connected to standard headphones. You load your audiogram, generate a DSP configuration, and hear the difference immediately. No soldering. No 3D printing. Just plug in and listen.

**Who it's for:** Anyone who wants to hear what personalised amplification sounds like before committing to a full build.

**What you get:** Real-time audio processing tuned to your audiogram, running on open-source hardware. Adjustable via the Tympan Remote App on your phone.

### Tier 2: Builder (~£450)

**What it is:** A Tympan board with BTE (Behind-The-Ear) earpieces and custom-moulded ear tips. This is a wearable hearing aid. You solder receiver wires, print ear moulds, build an MPO limiter circuit, and calibrate the system to your ears.

**Who it's for:** Someone comfortable with basic soldering and willing to spend a weekend on the build. Previous electronics experience helpful but not required — the [assembly guide](assembly/README.md) assumes zero experience.

**What you get:** A binaural hearing aid with WDRC compression, noise reduction, feedback cancellation, and hardware safety limiting. Comparable in function to a basic commercial hearing aid.

### Tier 3: Sovereign (~£550)

**What it is:** A fully custom integrated device. You print the complete shell on a resin printer, integrate all components into a single BTE housing, and calibrate with a measurement microphone. This is the endgame: a hearing aid you built entirely yourself.

**Who it's for:** Someone who wants full control over every aspect of their hearing device, and has the patience for iterative 3D printing and fitting.

**What you get:** A self-contained, sovereign hearing device. You own every layer — from the audiogram data to the DSP algorithms to the physical hardware on your ear.

---

## Sub-Modules

| Module | Description |
|---|---|
| [tympan/](tympan/README.md) | Tympan integration: audiogram-to-Arduino bridge, sketch generation, platform docs |
| [shell/](shell/README.md) | 3D printing guide for custom ear moulds: impressions, scanning, printing, fitting |
| [ite-shells/](ite-shells/README.md) | Custom In-The-Ear (ITE) shells: materials, sweat-proofing, full build workflow |
| [safety/](safety/README.md) | **Mandatory.** MPO limiters, calibration procedures, risk register, safety circuits |
| [assembly/](assembly/README.md) | Step-by-step build guide for all three tiers, assuming zero electronics experience |
| [sovereign_device/](sovereign_device/) | Phase 5 local audiogram → firmware + manifest pipeline and component database |
| [BOM.md](BOM.md) | Complete bill of materials with suppliers, costs, and substitution notes |
| [ROADMAP.md](ROADMAP.md) | Hardware development roadmap from documentation to sovereign device |

---

## Important: This Is Not a Medical Device

OpenHear hardware is a **Personal Sound Amplification Product (PSAP)** built by and for the user. It is not a regulated medical device. It has not been approved by any regulatory body. It is not sold, prescribed, or fitted by a clinician.

That said, the safety module is designed to **exceed commercial hearing aid safety margins**. The hardware MPO limiter cannot be overridden by software. The calibration procedure verifies output levels at every audiometric frequency. The risk register covers every failure mode we can identify.

You are the builder. You are the user. You are responsible for your own hearing health. If you are unsure about any aspect of this build, consult an audiologist. If in doubt, reduce gain. Hearing damage cannot be undone.

---

## Getting Started

1. Read the [safety module](safety/README.md). This is not optional.
2. Choose your [build tier](#build-tiers) and review the [BOM](BOM.md).
3. Follow the [assembly guide](assembly/README.md) for your tier.
4. Use `hardware/tympan/audiogram_to_tympan.py` to generate your personalised Arduino sketch from your audiogram.
5. Upload, calibrate, and listen.

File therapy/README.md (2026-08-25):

# OpenHear — Therapy (Pillar 5)

> **⚠️ EXPERIMENTAL — NOT A MEDICAL DEVICE**
> This is sovereign, inspectable tooling for *evidence-led self-experimentation*,
> not treatment. Nothing here diagnoses, treats, or cures anything. Talk to a
> professional before using frequency delivery for any health purpose.

First code for the therapeutic-frequency-delivery pillar in
[`docs/HUMAN_SENSORY_SOVEREIGNTY_ARCHITECTURE.md`](../docs/HUMAN_SENSORY_SOVEREIGNTY_ARCHITECTURE.md).
It begins with **binaural beats**, but with the angle that is genuinely
unexplored for OpenHear's users and missing from every consumer app.

## Why this is different

A binaural beat is the rhythm your brain perceives when each ear hears a
slightly different tone (e.g. 295 Hz left, 305 Hz right → a 10 Hz beat).
Generating that is trivial. The catch nobody addresses: **the percept needs
both tones to arrive at usable, balanced loudness.** For someone with hearing
loss — OpenHear's whole audience — a fixed carrier can land in a dead zone in
one ear and the beat simply collapses.

So `prescribe_binaural()` reads *your* audiogram and:

- places the **carrier** where both ears hear best, and
- sets **per-ear gains** that rebalance an asymmetric loss,

never exceeding a conservative amplitude ceiling. That is the part no
binaural-beats product does.

## Honesty about evidence

The science of brainwave entrainment is mixed, and most consumer claims are
overstated. Rather than hide that, every protocol carries an explicit
[`EvidenceGrade`](protocol.py) (`anecdotal → preliminary → emerging →
established`), and the bundled presets are graded conservatively — none
claims to be `established`. `target_outcomes` describe what a protocol is
*explored for*, not what it does.

## Safety

Auditory entrainment is contraindicated for seizure disorders. Every bundled
protocol declares that contraindication and `TherapeuticProtocol.gate()`
refuses to run when a user's declared conditions match. Amplitudes are capped
in `therapy/binaural.py`.

## Usage

```bash
# A plain 10 Hz (alpha) beat on a 300 Hz carrier:
python -m therapy.binaural_cli --beat 10 --carrier 300 --duration 60 --out beats.wav

# Personalised to your own audiogram (carrier + per-ear levels):
python -m therapy.binaural_cli --beat 10 --audiogram AG.json --out beats.wav
```

```python
from audiogram.audiogram import Audiogram
from therapy import prescribe_binaural, BRAINWAVE_PROTOCOLS

proto = BRAINWAVE_PROTOCOLS["alpha_relax"]
proto.gate(user_conditions={"epilepsy"})        # raises ContraindicationError
rx = prescribe_binaural(Audiogram.from_path("AG.json"), proto.frequencies[0])
signal = rx.render(duration_s=60)               # (N, 2) float32, ready to play
```

## Roadmap (Pillar 5, still open)

- Cross-modal entrainment via the wristband for profound loss where acoustic
  binaural beats can't work at all (isochronic/haptic rhythm over the
  existing 3-byte haptic packet).
- `carrier_shape` / `duty_cycle` rendering beyond pure sine.
- n-of-1 outcome logging and an evidence registry, per the architecture doc.

---

## Dermal profiles — 30–100 Hz haptic exploration

> **⚠️ EXPERIMENTAL — NOT A MEDICAL DEVICE.**
> The profiles in `therapy/dermal_profiles.py` are sovereign, inspectable
> parameters for self-experimentation. They do not diagnose, treat, or cure
> any condition. The mechanoreceptor references are descriptive of the
> published biophysics literature, not claims of therapeutic effect.
> Consult a medical professional before using any frequency-delivery tool
> for a health purpose.

`DermalProfile` wraps the standard `TherapeuticProtocol` model with two
extra constraints specific to skin-contact haptic delivery:

| Constraint | Value | Rationale |
|---|---|---|
| `MAX_SESSION_S` | 1200 s (20 min) | Prolonged vibration at one site can cause adaptation / numbness |
| `MAX_AMPLITUDE` | 120 / 255 | Prioritises comfort over intensity for sustained contact |

All bundled profiles carry `EvidenceGrade.ANECDOTAL` and a set of
skin-contact contraindications (open wounds, peripheral neuropathy,
pregnancy, etc.).  `DermalProfile.gate()` refuses to run when a user
declares a matching condition.

### Bundled profiles

| Key | Frequency | Receptor context (reference, not claim) |
|---|---|---|
| `gamma_low` | 30 Hz | Upper range of Meissner's corpuscle sensitivity (~20–50 Hz peak) |
| `gamma_mid` | 50 Hz | Crossover: Meissner declining, Pacinian corpuscle beginning to respond |
| `gamma_high` | 100 Hz | Rising slope of Pacinian corpuscle sensitivity |

### Usage

```python
from therapy.dermal_profiles import get_dermal_profile, DERMAL_PROFILES
from therapy.protocol import ContraindicationError

profile = get_dermal_profile("gamma_mid")

# Gate before any delivery — raises ContraindicationError if conditions match.
try:
    profile.gate(user_conditions)
except ContraindicationError as err:
    print(err)
    raise SystemExit(1)

# Integrate with the entrainment scheduler:
from therapy.entrainment import events_for_protocol
events = events_for_protocol(
    profile.protocol,
    intensity=profile.recommended_amplitude,
)
```

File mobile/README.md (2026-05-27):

# OpenHear — Android App

<!-- ⚠️ EXPERIMENTAL — NOT A MEDICAL DEVICE -->
<!-- Consult an audiologist before using any hearing device. -->
<!-- Use at your own risk. MIT Licensed. -->

> **⚠️ EXPERIMENTAL — NOT A MEDICAL DEVICE**
> Consult an audiologist before using any hearing device.
> Use at your own risk.

Real-time hearing assistance on Android. Captures mic input, processes it
through a sovereign DSP pipeline (no cloud, no telemetry), and streams the
result to Bluetooth hearing devices or earbuds.

**Current repo status:** the Android app is a public scaffold. The Compose UI,
audio engine wiring, and audiogram loader exist, but most DSP and Bluetooth
features below are still skeleton implementations rather than production-ready
hearing-aid processing.

## Features

| Category | Feature | Status |
|---|---|---|
| **DSP** | Multi-band compression (WDRC) | ✅ skeleton |
| **DSP** | Adaptive noise floor estimation | ✅ skeleton |
| **DSP** | Voice-emphasis filter | ✅ skeleton |
| **DSP** | Basic beamforming (dual-mic) | ✅ skeleton |
| **DSP** | On-device feedback cancellation (LMS) | ✅ skeleton |
| **DSP** | Own-voice detection bypass | ✅ skeleton |
| **DSP** | Safety limiter (hard clip at 0 dBFS) | ✅ skeleton |
| **Audiogram** | JSON audiogram loader | ✅ skeleton |
| **Audiogram** | Visual audiogram editor | 🔲 planned |
| **Learn** | Thumbs-up/down preference learner (v1) | ✅ skeleton |
| **Learn** | TinyML preference model (v2) | 🔲 roadmap |
| **Bluetooth** | ASHA streaming | 🔲 planned |
| **Bluetooth** | Classic A2DP / HFP streaming | 🔲 planned |
| **Bluetooth** | Auracast broadcast stub | 🔲 planned |
| **Monitoring** | Latency monitor (< 80 ms target) | ✅ skeleton |

## Architecture

```
┌─────────────────────────────────────────────────────┐
│                   Android App (Kotlin)              │
│                                                     │
│  ┌──────────┐  ┌──────────┐  ┌───────────────────┐  │
│  │ Audiogram │  │  Learn   │  │   Jetpack Compose │  │
│  │  Loader   │  │  Module  │  │       UI          │  │
│  └────┬─────┘  └────┬─────┘  └────────┬──────────┘  │
│       │              │                 │             │
│       ▼              ▼                 ▼             │
│  ┌──────────────────────────────────────────────┐    │
│  │            OboeEngine (Kotlin wrapper)       │    │
│  └──────────────────┬───────────────────────────┘    │
│                     │ JNI                            │
│  ┌──────────────────▼───────────────────────────┐    │
│  │         openhear_dsp.cpp (C++ / Oboe)        │    │
│  │                                              │    │
│  │  Mic ──► Noise ──► Compress ──► Voice ──►    │    │
│  │         Reduce     (WDRC)      Emphasis      │    │
│  │                                              │    │
│  │  ──► Feedback ──► Own-Voice ──► Limiter ──►  │    │
│  │      Cancel        Bypass       (0 dBFS)     │    │
│  │                                         BT   │    │
│  └──────────────────────────────────────────────┘    │
└─────────────────────────────────────────────────────┘
```

## Build Requirements

| Requirement | Version |
|---|---|
| Android Studio | Hedgehog (2023.1) or later |
| Android NDK | r25+ (for Oboe native build) |
| CMake | 3.22+ |
| Min SDK | 26 (Android 8.0) |
| Target SDK | 35 |
| Kotlin | 2.0+ |
| Jetpack Compose BOM | 2024.x |

```bash
# Clone and open in Android Studio
git clone https://github.com/ljbudgie/openhear.git
cd openhear/mobile
# Open this directory in Android Studio — Gradle sync will pull Oboe and Compose.
```

## Loading an Audiogram

The app accepts audiogram data as a JSON file matching the format used by
the Python `audiogram/loader.py` module in this repository:

```json
{
  "left": {
    "250": 20, "500": 25, "1000": 30,
    "2000": 40, "4000": 55, "8000": 60
  },
  "right": {
    "250": 15, "500": 20, "1000": 25,
    "2000": 35, "4000": 50, "8000": 55
  }
}
```

Load it from the app's **Audiogram** screen, or place the file at:
```
/sdcard/Android/data/org.openhear.app/files/audiogram.json
```

The loader computes per-frequency insertion gains using a half-gain rule and
a Pure Tone Average (PTA) from 500 / 1000 / 2000 Hz.

## Safety Disclaimer

**This software is NOT a medical device.** It is an experimental, open-source
hearing-assistance tool. Incorrect settings can damage hearing.

- Always start at low volume.
- Consult a licensed audiologist before relying on any hearing device.
- The planned safety limiter stage does **not** guarantee safe output levels
  for every listener; validate the full output chain on your own hardware.

## License

MIT — see [LICENSE](../LICENSE) in the repository root.

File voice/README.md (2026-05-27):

# voice/ — Vocal Frequency Analysis for OpenHear 🎙️

### Your voice. Your frequencies. Your development.

---

## What this is

This module provides real-time vocal frequency analysis for hearing aid users who want to develop their voice using accurate auditory feedback — possibly for the first time.

If you have sensorineural hearing loss, you have never heard your own voice through a clean, unprocessed signal.  Every adjustment you have ever made to your pitch, tone, or resonance was based on incomplete information.  Your brain has been guessing.

This module replaces the guessing with measurement.

---

## What this is not

This is **not** a voice cloner.  The reference comparison is a training target, not an imitation target.  The goal is not to sound like someone else — it is to understand your own vocal frequency profile and develop control over it.

The reference is a **mirror**, not a master.

---

## How it works

### The audiogram connection

The `audiogram/` module tells you which frequencies your ears cannot monitor.  This module tells you what your voice is doing in those exact frequency ranges.

If your audiogram shows a 60 dB loss at 4 kHz, you have never been able to hear whether your voice has energy at 4 kHz.  This module shows you — in real time — whether it does.

### The neuroplasticity principle

The brain develops vocal control through feedback loops.  Hearing listeners adjust their voice constantly based on what they hear.  If you cannot hear certain frequencies, you cannot adjust them.

Consistent, accurate visual feedback in those missing ranges allows the brain to build new motor-auditory associations.  This is not speculation — it is the same principle behind cochlear implant rehabilitation, speech therapy with spectrograms, and vocal training with real-time pitch displays.

The difference here is that you own the tool, you own the data, and you decide the target.

---

## Components

### `config.py` — User-tunable parameters

All analysis settings are plain Python constants.  Open the file, change a value, save.

| Parameter | Default | Purpose |
|---|---|---|
| `MIC_DEVICE_INDEX` | `None` | PyAudio device index (None = system default) |
| `SAMPLE_RATE` | `44100` | Capture sample rate in Hz |
| `FRAME_BUFFER` | `1024` | Samples per analysis frame |
| `REFERENCE_BANDPASS` | `(80, 8000)` | Vocal frequency isolation range (Hz) |
| `FORMANT_PEAKS` | `3` | Number of formant peaks to extract (F1, F2, F3) |
| `MATCH_TOLERANCE_DB` | `3.0` | Energy match threshold for green highlighting |
| `GAP_THRESHOLD_DB` | `6.0` | Energy gap threshold for red highlighting |

### `analyser.py` — Real-time vocal frequency analyser

Captures microphone input and extracts vocal features from each frame:
- **Fundamental frequency (F0):** your pitch in Hz
- **Formants (F1, F2, F3):** the resonant peaks that define vowel quality and vocal timbre
- **Spectral envelope:** the overall shape of your vocal energy across all frequencies
- **Harmonic-to-noise ratio (HNR):** how clear and periodic your voice is (higher = cleaner)
- **Energy (dBFS):** how loud the frame is

```python
from voice.analyser import open_mic_stream, capture_snapshot
from voice import config

# Open the microphone.
pa, stream = open_mic_stream()

try:
    # Capture and analyse one frame.
    snapshot = capture_snapshot(stream)

    print(f"Fundamental: {snapshot.fundamental_frequency_hz:.1f} Hz")
    print(f"Formants: {snapshot.formants}")
    print(f"HNR: {snapshot.hnr_db:.1f} dB")
    print(f"Energy: {snapshot.energy_db:.1f} dBFS")
finally:
    stream.stop_stream()
    stream.close()
    pa.terminate()
```

You can also analyse samples directly without a microphone:

```python
import numpy as np
from voice.analyser import analyse_frame

# Analyse a buffer of float32 samples.
samples = np.random.randn(1024).astype(np.float32) * 0.1
snapshot = analyse_frame(samples, sample_rate=44100)
```

### `reference.py` — Reference artist frequency profile loader

Loads a lossless recording (WAV or FLAC), isolates vocal frequencies, and computes an average spectral profile.  Export a track from your DAW or rip a lossless copy of an artist you want to study.

```python
from voice.reference import load_reference

# Load a reference track.
profile = load_reference("path/to/reference.wav", artist_name="Target Voice")

print(f"Artist: {profile.artist_name}")
print(f"Average formants: {profile.avg_formants}")
print(f"Dominant range: {profile.dominant_frequency_range}")
```

### `compare.py` — Real-time comparison engine

Compares your live voice against a reference profile across three frequency bands:
- **Low (80–300 Hz):** fundamental, chest resonance
- **Mid (300–2000 Hz):** vowel formants, vocal body
- **High (2000–8000 Hz):** consonant articulation, sibilance

```python
from voice.compare import compare

# Compare a live snapshot against the reference.
result = compare(snapshot, profile)

print(f"Band differences: {result.band_differences}")
print(f"Underused formants: {result.underused_formants}")
print(f"Similarity: {result.similarity_score:.0%}")
```

### `feedback.py` — Terminal-based real-time visual feedback

Renders a live frequency spectrum in the terminal with colour-coded comparison against the reference:

- 🟩 **Green bars:** your energy matches the reference within 3 dB
- 🟥 **Red bars:** your energy is more than 6 dB below the reference
- **Yellow `│`:** reference target line

```python
from voice.analyser import open_mic_stream, capture_snapshot
from voice.reference import load_reference
from voice.compare import compare
from voice.feedback import run_live
import numpy as np

# Load reference.
profile = load_reference("reference.wav")

# Open mic.
pa, stream = open_mic_stream()

def snapshot_gen():
    """Yield snapshots from the mic."""
    try:
        while True:
            yield capture_snapshot(stream)
    except KeyboardInterrupt:
        return

def compare_fn(snap):
    return compare(snap, profile)

try:
    run_live(snapshot_gen(), profile.spectral_envelope, compare_fn)
finally:
    stream.stop_stream()
    stream.close()
    pa.terminate()
```

---

## Dependencies

All dependencies are already in `requirements.txt`:
- **PyAudio** — microphone capture
- **NumPy** — FFT and array operations
- **SciPy** — peak detection, bandpass filtering, resampling
- **soundfile** *(optional)* — required only for FLAC file loading

---

## Data sovereignty

Your voice data never leaves your machine.  There is no cloud processing, no upload, no telemetry.  The microphone stream is analysed locally in real time and discarded after each frame unless you explicitly save it.

The reference profile is computed locally from a file you provide.  No reference data is bundled, downloaded, or scraped.

You own your voice.  This module helps you understand it.

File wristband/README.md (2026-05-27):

# OpenHear wristband v1.0.0 prototype

This is the release-facing home for the first Sharp Hearing clinic prototype.
The existing implementation stays in `stream/` and `hardware/wristband/`; this
directory gives the prototype one canonical path for firmware and setup docs.

## Canonical release paths

- Firmware to flash: `wristband/openhear_firmware.py`
- Live classifier wrapper: `yamnet_classifier.py`
- Audiogram-to-BLE command wrapper: `haptic_commander.py`
- End-to-end runtime: `stream/wristband_runtime.py`
- Legacy firmware mirror retained for compatibility: `hardware/wristband/firmware.py`

## Frozen v1.0.0 scope

The clinic prototype intentionally ships with seven sound classes only:

| Sound | Class ID | Pattern ID | Dominant frequency | Meaning |
|---|---:|---:|---:|---|
| silence | 0 | 0 | — | no haptic output |
| voice | 1 | 1 | 1000 Hz | speech and conversation |
| doorbell | 2 | 2 | 2000 Hz | doorbells and chimes |
| alarm | 3 | 3 | 3150 Hz | sirens, alarms, buzzers |
| dog | 4 | 4 | 500 Hz | barking and howls |
| traffic | 5 | 5 | 500 Hz | road traffic and horns |
| media | 6 | 6 | 1000 Hz | music, television, radio |

## Stable packet contract

Every Python sender and the micro:bit firmware use the same 3-byte BLE UART
packet:

```text
[sound_class_id, intensity, pattern_id]
```

- byte 0: stable sound class ID
- byte 1: audiogram-weighted intensity in the range `0..255`
- byte 2: stable haptic pattern ID

The intensity byte stays based on the current dominant-frequency lookup plus the
existing audiogram threshold buckets.

## micro:bit v2 motor mapping

- `P0` drives the **left** motor
- `P1` drives the **right** motor

The seven v1.0.0 patterns are unchanged from the prototype firmware.

## Windows clinic PC setup

1. Install Python 3.10+ on Windows.
2. Open PowerShell in the repository root.
3. Install dependencies:

   ```powershell
   py -m pip install -r requirements.txt
   ```

4. Download a local YAMNet `.tflite` file and keep its path on disk.
5. Use the bundled official label CSV at `stream/data/yamnet_class_map.csv`.
6. Pair or confirm visibility of the micro:bit advertising as `OpenHear`.

## Flashing and bench test

1. Open `wristband/openhear_firmware.py` in the micro:bit Python Editor or Mu.
2. Flash the board and confirm the display shows `H`.
3. Confirm the transistor stage uses `P0` for the left motor and `P1` for the right motor.
4. Run a dry packet check:

   ```powershell
   py -m haptic_commander --audiogram PATIENT.json --sound-class alarm --dry-run
   ```

5. Run a live BLE bench test:

   ```powershell
   py -m haptic_commander --audiogram PATIENT.json --sound-class alarm
   ```

6. Confirm the wristband renders the alternating alarm pattern.

## Sharp Hearing demo workflow

1. Export or save the patient audiogram as JSON.
2. Flash `wristband/openhear_firmware.py`.
3. Confirm the micro:bit advertises as `OpenHear`.
4. Optionally validate the live classifier alone:

   ```powershell
   py -m yamnet_classifier --model C:\models\yamnet.tflite --limit 10
   ```

5. Run the full wristband pipeline:

   ```powershell
   py -m stream.wristband_runtime --audiogram PATIENT.json --model C:\models\yamnet.tflite --labels stream/data/yamnet_class_map.csv
   ```

6. Trigger known sounds from the seven-class set and confirm that higher loss at
   the dominant frequency produces a stronger intensity byte and stronger haptic
   output.

## Noahlink status

Direct Noahlink extraction is not the release blocker for this prototype.
The wristband flow already consumes audiogram JSON, while direct parsing in
`core/read_fitting.py` and `audiogram/reader.py` still contains placeholder
frame parsing that needs confirmed real-device validation later.

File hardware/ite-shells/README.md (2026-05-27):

# ite-shells/ — Custom In-The-Ear Shells for OpenHear

> *Your ears. Your shell. Your sovereign sound.*

---

## What This Is

This module provides a complete guide to designing, printing, and finishing custom **In-The-Ear (ITE)** hearing aid shells for the OpenHear project. These shells house the full electronics package — microphone, Bluetooth streaming module, battery, and receiver — inside a single custom-fitted unit that sits entirely within your ear.

ITE shells are the natural next step beyond the BTE (Behind-The-Ear) moulds documented in [`hardware/shell/`](../shell/README.md). Where BTE moulds are acoustic couplers for an externally worn device, ITE shells *are* the device. Everything lives inside.

The goal: a shell that feels like skin, repels sweat, resists earwax, lasts for years, and fits your ear — and only your ear — perfectly. All made on a desktop resin printer.

---

## Why Custom ITE Shells?

### Benefits Over Commercial Shells

| Feature | Commercial ITE | OpenHear ITE |
|---|---|---|
| **Fit** | Made from your impression by a lab you never visit | Made from your scan, iterated by you until it's perfect |
| **Cost** | £200–£500 per shell from the manufacturer | £5–£15 in resin per shell, unlimited reprints |
| **Material choice** | Whatever the manufacturer uses | You choose biocompatible resin, flexible inserts, coatings |
| **Comfort** | One attempt, maybe one remake | Iterate until it disappears in your ear |
| **Sweat resistance** | Varies, often inadequate | Hydrophobic/omniphobic nano-coatings you apply yourself |
| **Aesthetics** | Limited colour options | Custom flesh-tone pigmentation, matte skin-like finish |
| **Repairability** | Send back to the lab, wait weeks, pay again | Reprint tonight |
| **Transparency** | Black-box process | Full control over every parameter |

### Philosophy

Commercial hearing aid shells are manufactured in centralised labs using proprietary scan-to-shell pipelines. You send an ear impression, a machine processes it, and a shell comes back. You have no input into the material, the wall thickness, the vent design, or the surface finish. If it doesn't fit, you send it back and wait.

OpenHear ITE shells invert this. You scan your own ear. You design the shell in open-source CAD software. You print it on your own printer. You coat it, sand it, test it, and wear it. If something is wrong, you change it and print again. The iteration loop is hours, not weeks.

This is sovereign hardware. You own the scan. You own the design file. You own the process.

---

## End-to-End Workflow Overview

The complete process from bare ear to finished shell:

```
1. Ear Scanning        →  Digital 3D model of your ear canal and concha
2. CAD Design           →  Shell with ports, vents, receiver bore, faceplate
3. Slicing & Printing   →  High-resolution resin print (0.025–0.05mm layers)
4. Post-Processing      →  Wash, cure, sand (1000–2000 grit), polish
5. Sweat-Proofing       →  Hydrophobic/omniphobic nano-coating application
6. Pigmentation         →  Flesh-tone colouring, matte finish
7. Assembly             →  Install OpenHear electronics, seal faceplate
8. Fitting & Testing    →  Comfort checks, acoustic verification, wear testing
```

Each step is documented in detail:

| Step | Guide |
|---|---|
| Materials selection | [materials.md](materials.md) |
| Sweat-proofing & coatings | [sweat-proofing.md](sweat-proofing.md) |
| Full workflow (scanning → assembly) | [workflow.md](workflow.md) |
| Resources, BOM, links | [resources.md](resources.md) |

---

## Recommended Printers

ITE shells demand high resolution because they sit inside the ear canal where every ridge is felt. SLA and DLP/MSLA resin printers are strongly preferred over FDM for this reason.

### Budget-Friendly (Under £300)

| Printer | Technology | XY Resolution | Layer Height | Build Volume | Price | Notes |
|---|---|---|---|---|---|---|
| **Elegoo Mars 4 Ultra** | MSLA | 35μm | 10–200μm | 153×77×165mm | ~£250 | Excellent price-to-precision. Community favourite |
| **Anycubic Photon Mono M5s** | MSLA | 19μm | 10–200μm | 218×123×200mm | ~£280 | Higher resolution LCD. Good for fine ear canal detail |
| **Elegoo Saturn 4 Ultra** | MSLA | 28μm | 10–200μm | 218×123×260mm | ~£300 | Larger build plate — print both shells and test pieces simultaneously |

### Mid-Range (£300–£800)

| Printer | Technology | XY Resolution | Layer Height | Build Volume | Price | Notes |
|---|---|---|---|---|---|---|
| **Phrozen Sonic Mini 8K** | MSLA | 22μm | 10–300μm | 165×72×180mm | ~£400 | 8K LCD — extremely fine detail |
| **Anycubic Photon Mono M7** | MSLA | 24μm | 10–200μm | 170×108×200mm | ~£450 | Fast print speeds with high accuracy |

### Professional (£1,000+)

| Printer | Technology | XY Resolution | Layer Height | Build Volume | Price | Notes |
|---|---|---|---|---|---|---|
| **Formlabs Form 3B+** | SLA (laser) | 25μm | 25–300μm | 145×145×185mm | ~£3,500 | Medical/dental validated. Best surface finish. Supports Formlabs BioMed resins directly |
| **Formlabs Form 4B** | SLA (MSLA hybrid) | 50μm | 25–200μm | 200×125×210mm | ~£4,500 | Newer platform. Faster than Form 3B+ |
| **SprintRay Pro 55S** | DLP | 49μm | 25–200μm | 192×120×200mm | ~£4,000 | Dental/audiology industry standard |

> **Recommendation:** For most makers, an **Elegoo Mars 4 Ultra** or **Anycubic Photon Mono M5s** at 0.03–0.05mm layer height produces shells that are indistinguishable in fit quality from professional lab shells. You do not need a Formlabs machine to make excellent ITE shells.

---

## ITE Shell Anatomy

An ITE shell is more than a hollow shape. It has specific functional features:

```
                    ┌─────────────────────┐
                    │     FACEPLATE       │  ← Removable cover for battery access
                    │  ┌───┐  ┌───┐      │
                    │  │MIC│  │VOL│      │  ← Microphone port, volume control
                    │  └───┘  └───┘      │
                    ├─────────────────────┤
                    │                     │
                    │   SHELL BODY        │  ← Custom-fitted to concha
                    │                     │
                    │   ┌─────────┐       │
                    │   │BATTERY  │       │  ← Battery compartment
                    │   └─────────┘       │
                    │                     │
                    │   ┌───────────────┐ │
                    │   │   RECEIVER    │ │  ← Balanced armature speaker
                    │   │   BORE       ─┼─┤  ← Sound output to ear canal
                    │   └───────────────┘ │
                    │        ║            │
                    │   ═════╝  VENT     ─┼─┤  ← Pressure equalisation channel
                    │                     │
                    └──────── CANAL TIP ──┘  ← Extends into ear canal
```

### Key Features

| Feature | Purpose | Typical Dimensions |
|---|---|---|
| **Shell body** | Houses all electronics, custom-fitted to concha | 1.2–2.0mm wall thickness |
| **Canal portion** | Extends into ear canal for acoustic seal and retention | 8–15mm length, follows canal curvature |
| **Faceplate** | Removable cover on the lateral (outer) face | 0.8–1.2mm thickness, snap-fit or friction-fit |
| **Receiver bore** | Channel for balanced armature speaker | 2.5–2.8mm diameter (see [materials in shell/](../shell/parametric_mould.md)) |
| **Vent channel** | Pressure equalisation, reduces occlusion | 0.8–2.5mm diameter (depends on hearing loss) |
| **Microphone port** | Opening for MEMS microphone | 1.0–1.5mm diameter, with wind guard recess |
| **Battery compartment** | Houses rechargeable LiPo cell | Sized to battery (typically 10×20×3mm for 100mAh) |
| **Wire routing channels** | Internal paths for connecting components | 1.0–1.5mm diameter |
| **Wax guard recess** | Holds replaceable cerumen filter at canal tip | 2.0mm diameter, 1.5mm depth |

---

## Safety & Legal Disclaimers

> **⚠️ EXPERIMENTAL PROJECT — NOT A MEDICAL DEVICE**
>
> OpenHear ITE shells are experimental personal projects. They have **not** been evaluated, approved, or cleared by any regulatory body (FDA, MHRA, CE/UKCA, TGA, or equivalent).
>
> In most jurisdictions, custom hearing aid shells fall under **Class II medical device** regulations when sold or distributed commercially. OpenHear shells are for **personal, experimental use only** and are not sold, distributed, or prescribed.

### Before You Build

1. **Consult an audiologist.** Get a professional hearing assessment. Know your audiogram. Understand your hearing loss type and severity before building any hearing device.

2. **Understand the risks.** Inserting any object into your ear canal carries risks including irritation, infection, allergic reaction, wax impaction, and in extreme cases, eardrum damage. Read the [safety module](../safety/README.md) completely.

3. **Test biocompatibility.** Even resins labelled "biocompatible" can cause reactions in sensitive individuals. Always perform a skin patch test (see [materials.md](materials.md)) before extended ear canal contact.

4. **Never exceed safe sound levels.** The [hardware MPO limiter](../safety/README.md) is mandatory for any powered ITE device. It caps maximum output regardless of software settings.

5. **Use at your own risk.** The authors of this guide are not responsible for any injury, hearing damage, allergic reaction, or other adverse outcome. This is an open-source project, not a medical product.

### Regulatory Context

| Jurisdiction | Relevant Regulation | Classification | Notes |
|---|---|---|---|
| UK | Medical Devices Regulations 2002 (as amended) | Class II (if sold) | Personal-use builds are not regulated as medical devices |
| EU | MDR 2017/745 | Class IIa (if placed on market) | Same — personal builds exempt from CE marking |
| USA | FDA 21 CFR Part 874 | Class II (if sold) | OTC hearing aid rules (2022) may apply to self-fit devices |
| Australia | TGA — Therapeutic Goods Act 1989 | Class IIa (if supplied) | Personal use is not "supply" under the Act |

> **This project does not constitute placing a medical device on the market.** You are building a device for your own personal use. However, if you make shells for others — even for free — you may be subject to medical device regulations in your jurisdiction. Do not distribute shells without understanding local laws.

---

## Getting Started

1. Read the [safety module](../safety/README.md). Non-negotiable.
2. Review [materials.md](materials.md) and choose your resin.
3. Follow the [workflow.md](workflow.md) step by step.
4. Apply sweat-proofing from [sweat-proofing.md](sweat-proofing.md).
5. Assemble with OpenHear electronics per the [assembly guide](../assembly/README.md).
6. Calibrate per the [safety module](../safety/README.md) before first powered use.

---

## Contributing

If you have printed ITE shells — share your experience. Open an issue with:
- Your printer model and resin
- Your post-processing workflow
- Fit quality and comfort notes
- Photos (if you are comfortable sharing)

Every data point makes the next person's shell better. That's the point.

---

*This module is part of [OpenHear](../../README.md) — sovereign audio for sovereign people.*
*MIT Licensed.*

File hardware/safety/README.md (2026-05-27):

# safety/ — Hearing Protection and Hardware Safety

**This module exists to prevent harm. Every other module in hardware/ is optional. This one is not.**

A hearing aid puts a speaker inside your ear canal. If that speaker plays sound that is too loud, it will damage your hearing permanently. This is not a theoretical risk. It is the primary failure mode of any amplification device, and it is irreversible.

Every design decision in this module prioritises one thing: **making it physically impossible for the device to produce sound loud enough to cause harm.** Software can crash, firmware can have bugs, users can set gain too high. The hardware limiter does not care. It is a circuit that clamps the electrical signal before it reaches the receiver, regardless of what the software is doing.

Read this entire document before building anything in the hardware/ module.

---

## 1. Maximum Power Output (MPO)

### What It Is

MPO is the loudest sound the hearing aid can produce, measured in dB SPL (decibels Sound Pressure Level) at the receiver output. Every commercial hearing aid has an MPO limit. OpenHear does too.

### Why It Matters

| Exposure | Duration to Damage |
|---|---|
| 85 dB SPL | 8 hours |
| 94 dB SPL | 1 hour |
| 100 dB SPL | 15 minutes |
| 110 dB SPL | Less than 2 minutes |
| 120 dB SPL | Pain threshold. Immediate risk |

A hearing aid receiver in an ear canal with a sealed mould can produce 110–120 dB SPL. Without limiting, a software bug or feedback oscillation could drive the receiver to maximum output and cause permanent hearing damage in seconds.

### How OpenHear Handles It

OpenHear uses **defence in depth** — multiple independent safety layers:

1. **Hardware MPO limiter** (this section) — a circuit that physically caps the electrical signal to the receiver. Cannot be overridden by software. Cannot be disabled by firmware bugs.
2. **Software safety layer** — digital peak limiter, gain ceiling, watchdog timer. Defence in depth. Works in normal operation but not relied upon as the sole protection.
3. **Calibration procedure** — measures actual SPL output and verifies it matches expected values.

---

## 2. Hardware MPO Limiter Circuit

This is the most important circuit in the entire build. It is simple, cheap, and it prevents hearing damage.

### How It Works

A pair of back-to-back zener diodes clamps the voltage across the receiver. When the signal voltage exceeds the zener voltage, the diodes conduct and shunt the excess energy through a series resistor. The receiver never sees more than the zener voltage, regardless of what the amplifier is doing.

This is a passive circuit. It has no power supply, no microcontroller, no firmware. It cannot crash, hang, or be misconfigured by software. It works by physics.

### Circuit Design

```
                     R_series (100Ω)
Amplifier Output ───/\/\/\/──┬──── Receiver (+)
                             │
                          ┌──┴──┐
                          │     │
                        ┌─┤     ├─┐
                        │ │ ZD1 │ │
                        │ └──┬──┘ │
                        │    │    │
                        │ ┌──┴──┐ │
                        │ │ ZD2 │ │
                        │ └──┬──┘ │
                        └────┤────┘
                             │
Ground ──────────────────────┴──── Receiver (-)
```

**Components:**
- **R_series:** 100Ω resistor in series with the receiver. Limits current and dissipates excess power as heat. Use a 1/4W or higher rated resistor.
- **ZD1 and ZD2:** Zener diodes connected back-to-back (anode-to-anode). This clamps the signal symmetrically in both polarities. The zener voltage determines the MPO.

### Component Values for Different MPO Targets

The zener voltage determines the maximum voltage across the receiver, which determines the maximum SPL output. Select based on the user's UCL (Uncomfortable Loudness Level).

| Target MPO (dB SPL) | Zener Voltage | Series Resistor | Zener Part Number | Notes |
|---|---|---|---|---|
| 90 dB SPL | 0.47V | 100Ω | BZX79-C0V47 | Very conservative. For mild loss with normal UCL |
| 100 dB SPL | 1.5V | 100Ω | BZX79-C1V5 | Conservative. For moderate loss |
| 110 dB SPL | 4.7V | 100Ω | BZX79-C4V7 | Standard. For moderately-severe to severe loss |
| 120 dB SPL | 15V | 100Ω | BZX79-C15 | Maximum. For profound loss only. This is the absolute ceiling — never exceed this |

> **Important:** These values are approximate and depend on the specific receiver model's sensitivity (SPL per volt). The [calibration procedure](#4-calibration-procedure) verifies the actual output. Always calibrate after building the limiter circuit. If measured MPO exceeds the target, use a lower zener voltage.

> **When in doubt, use a lower zener voltage.** A limiter that is too conservative reduces maximum volume. A limiter that is too permissive risks hearing damage. There is no symmetry here — one outcome is inconvenient, the other is permanent.

### The Critical Property

**This circuit CANNOT be overridden by software.**

No firmware update, no configuration change, no bug, no hack can make the receiver produce more than the clamped voltage. The zener diodes are passive components. They do not execute code. They do not have an off switch. They are always active.

This is intentional. The hardware limiter is the last line of defence, and it must be unconditionally reliable.

---

## 3. Software Safety Layer (Defence in Depth)

The hardware limiter is the primary safety mechanism. The software safety layer is the secondary mechanism. It handles things the hardware limiter cannot — like detecting abnormal conditions and muting output before the limiter even needs to engage.

### Digital Peak Limiter

The Tympan sketch includes a digital peak limiter that prevents the DSP output from exceeding a configurable maximum level. This is set below the hardware limiter threshold so that in normal operation, the hardware limiter never activates.

```
Software limiter threshold: MPO - 5 dB (safety margin)
Hardware limiter threshold: MPO (absolute maximum)
```

The 5 dB gap means the software limiter handles normal peaks, and the hardware limiter only engages if the software fails.

### Maximum Gain Ceiling

Each frequency channel has a maximum gain ceiling that cannot be exceeded regardless of the audiogram-derived gain target. This prevents a data entry error or corrupted audiogram file from producing dangerous gain values.

| Frequency Range | Maximum Gain Ceiling |
|---|---|
| 125–500 Hz | 50 dB |
| 500–2000 Hz | 55 dB |
| 2000–8000 Hz | 60 dB |

These ceilings are set in the Arduino sketch and are not adjustable via the Tympan Remote App.

### Startup Self-Test

When the Tympan powers on, the sketch runs a self-test before enabling audio output:

1. **Mute output** — receivers are silent during self-test
2. **Check input levels** — verify microphone signals are within expected range (not open-circuit, not shorted)
3. **Check output path** — send a sub-audible test tone and verify the signal path is intact
4. **Verify MPO limiter** — send a brief over-limit signal and verify the output is clamped (requires measurement circuit, optional)
5. **Enable output** — if all tests pass, unmute and begin normal operation
6. **If any test fails** — remain muted, flash error LED, log error to SD card

### Watchdog Timer

A hardware watchdog timer monitors the DSP processing loop. If the DSP stalls (crashes, hangs, enters an infinite loop), the watchdog triggers and mutes the output within 10ms.

**Why this matters:** A DSP stall could leave the last output sample playing continuously. If that sample happens to be at maximum amplitude, the receiver would produce a continuous loud tone. The watchdog prevents this by muting the output if the DSP doesn't "check in" within 10ms.

---

## 4. Calibration Procedure

Calibration verifies that the actual sound output matches the expected output at every frequency. It must be done after every hardware change and after every configuration change.

### Equipment Needed

- Calibration microphone: Dayton Audio iMM-6 or equivalent with known sensitivity
- 2cc coupler (simulates the volume of a sealed ear canal) — can be 3D printed or purchased
- Audio signal generator (software: REW, Audacity, or similar)
- SPL meter app or measurement software calibrated to the microphone

### Procedure

1. **Connect the ear mould to the 2cc coupler.** The coupler simulates the ear canal volume. Place the calibration microphone at the measurement port.

2. **Generate known-level tones.** Play pure tones at each audiometric frequency (250, 500, 1000, 2000, 3000, 4000, 6000, 8000 Hz) through the hearing aid at the programmed gain level.

3. **Measure SPL at each frequency.** Record the measured dB SPL. Compare with the expected output (input level + programmed gain at that frequency).

4. **Verify MPO at each frequency.** Increase the input level until the output reaches the expected MPO limit. Verify that the output does not exceed the target MPO. The hardware limiter should engage and cap the output.

5. **Log results to SD card.** The Tympan sketch logs calibration measurements for future reference.

6. **Pass/fail criteria:**
   - Output at programmed gain: within ±3 dB of target at all frequencies
   - MPO limit: must not exceed target MPO at any frequency
   - If MPO is exceeded at any frequency: **stop, do not use the device, check the hardware limiter circuit**

### When to Recalibrate

- After any configuration change (gain, compression, MPO targets)
- After replacing the receiver
- After reprinting or modifying the ear mould
- After replacing the battery
- Every 3 months during regular use
- Whenever the device sounds "different" — trust your ears, then verify with measurements

---

## 5. Risk Register

Every identified failure mode, its potential harm, and how OpenHear mitigates it.

| # | Risk | Severity | Likelihood | Mitigation | Residual Risk |
|---|---|---|---|---|---|
| 1 | Software bug produces loud output | **Critical** — hearing damage | Medium | **Hardware zener clamp** caps output regardless of software state. Cannot be overridden | Low — hardware limiter is passive and unconditional |
| 2 | Receiver failure (shorted voice coil) | **Critical** — loud transient | Low | **Hardware clamp** limits transient amplitude. **Watchdog timer** mutes within 10ms if DSP detects anomaly | Low |
| 3 | Feedback oscillation (whistling) | **High** — sustained loud tone | Medium | **Hardware clamp** caps amplitude. **Adaptive feedback cancellation** in DSP. **Gain ceiling** prevents runaway loop gain | Low — three independent mitigations |
| 4 | User sets gain too high | **High** — gradual hearing damage from chronic overexposure | Medium | **Software warning** when gain exceeds recommended levels. **Hardware clamp** prevents acute damage. **Gain ceiling** in firmware | Medium — user can override software warnings. Hardware clamp prevents acute harm but not chronic overexposure at levels below MPO |
| 5 | Battery voltage sag under load | **Medium** — unpredictable DSP behaviour | Medium | **Low-battery detection** in firmware. **Graceful shutdown** with user notification. Tympan hardware includes voltage monitoring | Low |
| 6 | Ear mould causes physical discomfort or injury | **Medium** — ear canal irritation or injury | Low | **Fitting guide** with safety warnings. **Maximum insertion depth** specified. **Biocompatible resin** required. **Wear testing protocol** | Low — following the fitting guide minimises risk |
| 7 | Uncured resin causes skin reaction | **Medium** — chemical irritation or allergic reaction | Low | **Post-processing guide** specifies full UV cure. **Biocompatible resin** required. Itching noted as warning sign requiring investigation | Low |
| 8 | Calibration drift over time | **Low** — gradual change in output levels | Medium | **Recalibration schedule** (every 3 months). **Calibration logging** for trend detection | Low |

---

## 6. Statement of Responsibility

**OpenHear is not a regulated medical device.** It has not been submitted to or approved by any regulatory body including the FDA, CE/UKCA, or any equivalent authority. It is not sold, prescribed, dispensed, or fitted by a licensed professional.

**You build this device. You use this device. You are responsible for your own hearing health.**

The safety module described in this document is designed to **exceed the safety margins of commercial hearing aids.** The hardware MPO limiter is a passive, unconditional circuit that cannot be overridden by software. The calibration procedure verifies actual output levels. The risk register identifies and mitigates every failure mode we can identify.

But no safety system is perfect. Components can fail. Designs can have flaws we haven't identified. Your hearing is irreplaceable.

**If in doubt, reduce gain.** A hearing aid that is slightly too quiet is inconvenient. A hearing aid that is too loud causes permanent damage. There is no symmetry between these outcomes.

**If something sounds wrong, remove the device immediately.** Pain, sudden loudness changes, or unusual sounds are all signals to stop using the device and investigate before continuing.

**Hearing damage cannot be undone.** Act accordingly.

---

## Files in This Module

| File | Description |
|---|---|
| `README.md` | This document. Safety design, MPO limiter circuit, calibration procedure, risk register |
| `mpo_calculator.py` | Python script: takes an audiogram, calculates recommended MPO limits and component values per frequency |

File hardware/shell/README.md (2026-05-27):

# shell/ — 3D Printed Custom Ear Moulds

This guide walks you through making custom ear moulds for your OpenHear hearing aid. Custom moulds matter because they create an acoustic seal between the receiver (speaker) and your ear canal. A good seal means better bass response, less feedback, and all-day comfort. A bad seal means whistling, tinny sound, and a device you take out after an hour.

Every ear is different. That's the whole point of custom moulds.

---

## Overview of the Process

1. Take ear impressions with medical silicone
2. Scan the impressions to create 3D models (STL files)
3. Prepare the STL in Meshmixer or Blender (add vent channel, receiver bore, sound tube)
4. Print on a resin printer at 0.05mm layer height
5. Post-process (wash, cure, sand)
6. Fit, test, and iterate

Total time: 2–3 days including print time and cure time. Active work: about 4–6 hours spread across those days.

---

## Step 1: Taking Ear Impressions

You are making a physical copy of your ear canal and concha (the bowl-shaped part of your outer ear). This is done with two-part medical-grade silicone that you mix and inject into your ear.

### What You Need

- Two-part medical silicone ear impression kit (available on Amazon, ~£15)
- Foam ear dams (otoblock) — these should be included in the kit
- Otoscope or penlight (to check ear canal is clear of wax)
- A helper — do not do this alone

### ⚠️ Safety Warnings

> **Do not skip the foam dam.** The foam dam (otoblock) sits in your ear canal before the silicone. It prevents silicone from going too deep. Without it, silicone can reach your eardrum and cause serious injury.

> **Do not insert anything into your ear canal if you have pain, infection, discharge, or a perforated eardrum.** See a clinician first.

> **Have someone help you.** You cannot see your own ear canal. A helper can position the foam dam correctly and inject the silicone evenly.

> **Maximum insertion depth:** The foam dam should sit at the second bend of the ear canal, approximately 15–20mm from the canal entrance. If you are unsure, use a shorter impression. A short impression is safe. A too-deep impression is dangerous.

### Technique

1. **Check the ear canal** with an otoscope or penlight. It should be clean and free of excessive wax. If you see a wax blockage, have it removed by a professional before proceeding.

2. **Insert the foam dam.** Using the included insertion tool, gently place the foam dam into the ear canal. It should sit snugly at the second bend. You should feel mild pressure but no pain. If it hurts, stop and reposition.

3. **Mix the silicone.** Follow the kit instructions — typically equal parts base and catalyst, mixed for 30 seconds until the colour is uniform. You have about 2–3 minutes of working time before it sets.

4. **Inject into the ear.** Using the syringe, fill the ear canal from the foam dam outward. Fill the concha (bowl of the ear) completely. Overfill slightly — you can trim excess later.

5. **Hold still for 5 minutes.** The silicone needs to fully cure. Don't talk, chew, or move your jaw.

6. **Remove by pulling down and out** on the earlobe while gently wiggling the impression. It should come out in one piece. If it tears, redo it — a torn impression will produce a bad scan.

7. **Inspect the impression.** You should see clear detail of the ear canal, the concha, and the helix. The canal portion should be at least 10mm long. If it's too short, the mould won't seal properly.

8. **Repeat for the other ear.**

---

## Step 2: Scanning Impressions

Convert your physical silicone impressions into 3D digital models (STL files).

### Recommended Scanning Apps

| App | Platform | Cost | Notes |
|-----|---|---|---|
| [Polycam](https://poly.cam/) | iOS (LiDAR) | Free tier available | Best results with iPhone 12 Pro or newer. Use LiDAR mode, not photo mode |
| [Qlone](https://www.qlone.pro/) | iOS / Android | Free with watermark | Use the printed scanning mat for best results |
| [Kiri Engine](https://www.kiriengine.com/) | iOS / Android | Free tier available | Cloud processing, works with any phone camera |

### Scanning Tips

- Place the impression on a contrasting background (white impression on dark surface)
- Use even, diffuse lighting — avoid harsh shadows
- Scan slowly, overlapping each angle
- Capture at least 50 photos / angles for photogrammetry apps
- Export as STL or OBJ format

### Alternative: Desktop 3D Scanner

If you have access to a desktop 3D scanner (e.g., Revopoint POP, Creality CR-Scan), use it. Desktop scanners produce more accurate results than phone-based photogrammetry, especially for the small details of the ear canal.

---

## Step 3: Preparing the STL

The raw scan gives you the outer shape of your ear. You now need to add internal channels for the receiver (speaker), vent (pressure equalisation), and sound tube.

### Software Options

| Software | Cost | Notes |
|---|---|---|
| [Meshmixer](https://meshmixer.com/) | Free | Best for boolean operations on organic shapes. Recommended |
| [Blender](https://www.blender.org/) | Free | More powerful but steeper learning curve |

### Operations

1. **Clean the scan.** Remove any scanning artifacts, fill small holes, smooth rough surfaces. In Meshmixer: Edit → Make Solid → Smooth.

2. **Trim to mould shape.** Cut the impression to the correct length — you want the canal portion plus enough concha to anchor the mould in your ear. Leave 2–3mm of margin.

3. **Hollow the mould.** The mould should be a shell, not a solid block. Target wall thickness: 1.5–2.0mm. In Meshmixer: Edit → Hollow.

4. **Add the receiver bore.** This is the hole where the balanced armature receiver sits. See [parametric_mould.md](parametric_mould.md) for exact dimensions based on your receiver model. The bore runs from the tip of the canal portion to a pocket where the receiver body sits.

5. **Add the vent channel.** The vent equalises pressure and reduces the occlusion effect (the "plugged up" feeling). Vent size depends on your hearing loss — see the vent sizing guide below. The vent runs parallel to the receiver bore, from the canal tip to the outer surface of the mould.

6. **Add the sound tube channel.** If using a sound tube instead of a direct receiver, add a 1.93mm ID channel (standard #13 tubing). See [parametric_mould.md](parametric_mould.md) for details.

7. **Export as STL** at maximum resolution for printing.

### Vent Sizing Guide

The vent channel equalises pressure between the sealed ear canal and the outside. Larger vents reduce the occlusion effect but also reduce bass amplification (low-frequency sound leaks out through the vent). Choose based on your hearing loss:

| Hearing Loss | Vent Diameter | Vent Type | Rationale |
|---|---|---|---|
| Severe-to-profound (71+ dB) | 0.8mm | Pressure vent | Maximum seal. You need all the bass amplification you can get. The small vent only equalises static pressure |
| Moderate (41–70 dB) | 1.5mm | Standard vent | Balance between seal and comfort. Some bass leakage is acceptable |
| Mild (26–40 dB) | 2.5mm | Open vent | Comfort is more important than seal. Natural bass hearing is mostly intact. Larger vent reduces occlusion |

### Receiver Bore Dimensions

The receiver (balanced armature speaker) sits inside the mould. The bore must be sized to fit the specific receiver model with a snug fit.

| Receiver | Bore Diameter | Bore Length | Notes |
|---|---|---|---|
| Knowles ED-29689 | 2.5mm | 8.0mm | 0.1mm tolerance. Friction fit — no adhesive needed if sized correctly |
| Knowles WBFK-30019 | 2.8mm | 9.5mm | 0.1mm tolerance |
| Knowles WBFK-30095 | 2.8mm | 9.5mm | Same housing as WBFK-30019 |

---

## Step 4: Printing

### Recommended Printers

| Printer | Resolution | Build Volume | Price | Notes |
|---|---|---|---|---|
| Elegoo Mars 4 | 0.05mm (50μm) | 132×74×150mm | ~£200 | Recommended. Good resolution for ear moulds |
| Anycubic Photon Mono 2 | 0.05mm | 143×89×165mm | ~£180 | Good alternative |
| FormLabs Form 3 | 0.025mm | 145×145×185mm | ~£2500 | Professional quality. Overkill for most users |

### Resin Selection

**You must use biocompatible resin for anything that contacts your skin or ear canal.**

| Resin | Type | Skin Contact | Price | Notes |
|---|---|---|---|---|
| Elegoo Bio Resin | Plant-based, Class I biocompatible | Yes (after full UV cure) | ~£40/500ml | Recommended. Low odour, easy to work with |
| FormLabs BioMed Clear | Class I biocompatible | Yes | ~£150/L | Medical grade. Expensive |
| Siraya Tech Tenacious | Flexible, biocompatible | Yes (after full cure) | ~£50/500ml | Good for comfort — slightly flexible moulds |

> **Warning:** Standard resin (not labelled biocompatible) can cause skin irritation, allergic reactions, or chemical burns. Do not use standard resin for ear moulds. This is not optional.

### Print Settings

- **Layer height:** 0.05mm (50μm) — this gives a smooth surface that won't irritate the ear canal
- **Exposure time:** Per resin manufacturer's recommendation (typically 2–3 seconds per layer)
- **Bottom exposure:** Per manufacturer (typically 30–45 seconds for first 5 layers)
- **Orientation:** Print the mould at 45° angle with the canal tip pointing up. This minimises support marks on the canal surface
- **Supports:** Light supports only. Remove support contact points from canal surface before fitting

---

## Step 5: Post-Processing

### Washing

1. Remove the print from the build plate
2. Wash in **99% IPA (isopropyl alcohol)** for 3–5 minutes. Use an ultrasonic cleaner or agitate by hand
3. Rinse with fresh IPA
4. Air dry completely (10–15 minutes)

> **Wear nitrile gloves.** Uncured resin is a skin irritant. Do not touch the print with bare hands until after UV curing.

### UV Curing

1. Place the washed, dry print in a UV curing station (405nm)
2. Cure for the time specified by your resin manufacturer (typically 10–30 minutes)
3. Rotate the print halfway through for even curing
4. **The mould must be fully cured before any skin contact.** Undercured resin is not biocompatible regardless of what it says on the bottle

### Sanding

1. Sand any rough spots with 400-grit wet sandpaper
2. Follow with 800-grit for a smooth finish
3. Pay special attention to the canal portion — any roughness will cause discomfort
4. The surface should feel smooth and polished when you run your fingernail across it

---

## Step 6: Fitting and Testing

### First Fit

1. **Inspect the mould** for sharp edges, rough surfaces, or printing artifacts. Sand anything that doesn't feel smooth
2. **Insert gently.** The mould should slide in with light pressure. If it requires force, it's too tight — sand down or reprint
3. **Check the seal.** With the mould inserted, you should feel a slight reduction in ambient sound (occlusion). If you hear normally, the seal is poor — the mould may be too loose or the canal portion too short
4. **Check comfort immediately.** Any pain means remove it and investigate. Pain is never acceptable

### Wear Testing

| Duration | What to Check |
|---|---|
| 1 hour | Comfort, seal quality, any pressure points |
| 4 hours | Sustained comfort, any developing soreness, any itching (possible resin sensitivity) |
| 8 hours | Full-day wearability, moisture buildup, any loosening |

### Iteration

This is normal. Most people need 2–3 iterations to get the fit right.

| Problem | Fix |
|---|-----|
| Too tight (pain, pressure) | Sand down the canal portion by 0.1–0.2mm, or reprint with 0.2mm offset |
| Too loose (falls out, poor seal) | Reprint with -0.1mm offset (slightly larger), or add a thin layer of medical-grade silicone |
| Feedback (whistling) | Usually means a seal leak. Check for gaps between mould and ear canal. May need a longer canal portion |
| Occlusion (own voice sounds boomy) | Increase vent diameter by 0.5mm. This trades some bass amplification for comfort |
| Itching after extended wear | Check that resin is fully cured. Re-cure under UV for 30 more minutes. If itching persists, try a different resin — you may be sensitive to this formulation |
| Discomfort at one specific point | Mark the pressure point on the mould with a marker, remove, and sand that specific area |

---

## Safety Reminders

- **Never force a mould into your ear.** If it doesn't fit easily, sand it down or reprint.
- **Maximum canal depth:** The mould canal should not extend deeper than 15mm past the canal entrance. Deeper insertion risks contact with the eardrum.
- **Inspect before every use.** Check for cracks, rough spots, or degradation. Replace any mould that shows wear.
- **Clean regularly.** Wipe with IPA or mild soap and water after each use. Allow to dry fully before reinserting.
- **Replace every 6–12 months**, or sooner if the fit changes or the mould shows degradation.

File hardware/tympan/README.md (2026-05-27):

# tympan/ — Tympan Integration

This module connects OpenHear's audiogram-driven software pipeline to the [Tympan](https://tympan.org/) open-source hearing aid development board.

---

## Why Tympan?

The Tympan is the only open-source hearing aid hardware platform with validated clinical performance. Here's why OpenHear builds on it:

- **Open source.** Hardware schematics, firmware, and DSP algorithms are all publicly available under open licences. No black boxes.
- **Clinical validation.** Developed with NIH (National Institutes of Health) funding. The WDRC (Wide Dynamic Range Compression) algorithms have been tested in clinical settings.
- **Active community.** Forum, GitHub issues, and a development team that responds. You are not building alone.
- **Programmable via Arduino IDE.** If you can upload a sketch, you can program a hearing aid. No proprietary toolchain required.
- **Low latency.** Under 3ms input-to-output latency. You will not hear a delay — this is critical for a natural listening experience.
- **High sample rate.** Supports up to 96 kHz sample rate for full-bandwidth audio processing.
- **Hardware:** Teensy 4.1 based, 600 MHz ARM Cortex-M7 processor. More than enough power for real-time multi-band compression, noise reduction, and feedback cancellation simultaneously.
- **Earpiece design.** Tympan has an open-source BTE-RIC (Behind-The-Ear, Receiver-In-Canal) earpiece design with dual MEMS microphones.
- **Arduino library.** Includes WDRC, noise reduction, feedback cancellation, and frequency shifting algorithms ready to use.

### Platform Status

- **Rev F** is the current production board. This is what OpenHear targets.
- **Rev G** is in development. OpenHear will support it when it ships.

---

## Data Flow: Audiogram to Hearing Aid

```
┌──────────────────┐
│  Audiogram JSON   │  Your hearing test data (openhear-audiogram-v1 format)
│  (.json file)     │
└────────┬─────────┘
         │
         ▼
┌──────────────────┐
│  audiogram.loader │  Python: load_audiogram(), get_thresholds(), get_pta()
│  audiogram.export │  Python: get_gain_profile(), to_dsp_config()
└────────┬─────────┘
         │
         ▼
┌──────────────────────────┐
│  audiogram_to_tympan.py  │  Python: reads gain profile + DSP config,
│  (this module)           │  generates a complete Arduino .ino sketch
└────────┬─────────────────┘
         │
         ▼
┌──────────────────┐
│  Arduino IDE      │  Upload the generated .ino sketch to Tympan
└────────┬─────────┘
         │
         ▼
┌──────────────────┐
│  Tympan Rev F     │  Real-time audio processing tuned to YOUR audiogram
│  (on your ear)    │  WDRC + noise reduction + feedback cancellation
└──────────────────┘
```

### Step by Step

1. **Start with your audiogram.** You need a hearing test in `openhear-audiogram-v1` JSON format. See [`audiogram/data/FORMAT.md`](../../audiogram/data/FORMAT.md) for the format specification and [`audiogram/data/burgess_2021.json`](../../audiogram/data/burgess_2021.json) for a real example.

2. **Generate a Tympan sketch.** Run the bridge script:

   ```bash
   # For one ear (right ear by default):
   python -m hardware.tympan.audiogram_to_tympan audiogram/data/burgess_2021.json output.ino

   # For binaural (both ears):
   python -m hardware.tympan.audiogram_to_tympan audiogram/data/burgess_2021.json output.ino --binaural
   ```

   This reads your audiogram, computes gain profiles and DSP parameters using OpenHear's audiogram module, and writes a complete Arduino sketch file.

3. **Open in Arduino IDE.** Open the generated `.ino` file. Install the [Tympan Library](https://github.com/Tympan/Tympan_Library) via Arduino Library Manager if you haven't already.

4. **Upload to Tympan.** Connect your Tympan via USB, select the Teensy 4.1 board, and upload. The sketch includes a startup self-test that verifies the MPO limiter is active.

5. **Fine-tune via Tympan Remote App.** The generated sketch enables Bluetooth control. Use the [Tympan Remote App](https://play.google.com/store/apps/details?id=com.creare.tympanRemote) to adjust gain, compression, and noise reduction in real time.

---

## Files in This Module

| File | Description |
|---|---|
| `audiogram_to_tympan.py` | Python bridge: reads audiogram JSON, generates Arduino .ino sketch |
| `templates/basic_openhear.ino` | Arduino template with placeholder values filled by the bridge script |

---

## Tympan Resources

- **Website:** [tympan.org](https://tympan.org/)
- **Shop:** [shop.tympan.org](https://shop.tympan.org/)
- **GitHub (hardware):** [github.com/Tympan/Tympan_Rev_F](https://github.com/Tympan/Tympan_Rev_F)
- **GitHub (library):** [github.com/Tympan/Tympan_Library](https://github.com/Tympan/Tympan_Library)
- **Documentation wiki:** [github.com/Tympan/Docs/wiki](https://github.com/Tympan/Docs/wiki)
- **Forum:** [forum.tympan.org](https://forum.tympan.org/)
- **Arduino library install:** Search "Tympan" in Arduino IDE Library Manager, or clone from GitHub

---

## Tympan Arduino Library: Key Algorithms

The Tympan Library provides these DSP algorithms out of the box. The generated sketch uses all of them:

| Algorithm | What It Does | Why It Matters |
|---|---|---|
| **WDRC** (Wide Dynamic Range Compression) | Makes quiet sounds louder and loud sounds quieter, per frequency band | Core hearing aid function. Matches amplification to your hearing loss at each frequency |
| **Noise Reduction** | Reduces steady-state background noise (fans, traffic, hum) | Improves speech clarity in noisy environments |
| **Feedback Cancellation** | Detects and suppresses acoustic feedback (whistling) | Prevents the high-pitched squeal that occurs when amplified sound leaks from the ear canal back to the microphone |
| **Frequency Shifting** | Shifts high frequencies down to ranges with better hearing | Useful for severe high-frequency loss where amplification alone is not enough |

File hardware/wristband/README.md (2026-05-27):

# OpenHear wristband prototype hardware assets

This directory keeps the original prototype firmware path for compatibility.

## Canonical v1.0.0 docs and firmware

- Release-facing setup guide: [`../../wristband/README.md`](../../wristband/README.md)
- Canonical firmware file to flash: [`../../wristband/openhear_firmware.py`](../../wristband/openhear_firmware.py)
- Legacy firmware mirror retained here: [`firmware.py`](firmware.py)

## Wiring and Windows support

- Full wiring notes: [`../../HARDWARE.md`](../../HARDWARE.md)
- Flashing steps: [`../../HARDWARE.md#firmware-flashing-windows`](../../HARDWARE.md#firmware-flashing-windows)
- BLE troubleshooting: [`../../HARDWARE.md#windows-ble-debugging-checklist`](../../HARDWARE.md#windows-ble-debugging-checklist)

## v1.5 No-Solder Modular Edition

For complete beginners, start with [`v1.5-no-solder/`](v1.5-no-solder/): the Modular Lego build that uses pre-made dev boards, magnetic pogo or JST connectors, snap-fit printed bays, USB flashing, and pre-wired actuators. It is slightly larger and about 10-15% more expensive than compact v1, but it is the recommended Print & Done path with no soldering, crimping, wire stripping, or special electronics tools.

Compact v1 remains the advanced/smallest option for experienced builders.

## Aids-free wristband v1 DIY prototype assets

The v1 directory assets move the project toward `docs/AIDS_FREE_ARCHITECTURE.md`:
wrist-only capture, local processing, skin-as-transducer output, and no cloud or
ear-worn dependency.

```text
hardware/wristband/
├── BOM.csv
├── assembly_v1.md
├── power_budget_v1.md
├── cad/
│   ├── generate_stl.sh
│   └── parametric_wristband_v1.scad
├── firmware/
│   ├── haptic_mapper.py
│   └── openhear_firmware_v1.py
└── kicad/
    ├── gerber_notes.md
    ├── wristband_v1.kicad_pcb
    ├── wristband_v1.kicad_pro
    └── wristband_v1.kicad_sch
```

Start with the 24-actuator configuration unless you already have a current-limited
bench supply, thermal logging, and dense flex-harness experience. The 64- and
128-actuator variants are research targets, not first wearable builds.

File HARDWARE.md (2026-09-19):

# HARDWARE.md — Noahlink Wireless 2 Setup & Fitting Software

This document covers the physical setup of the Noahlink Wireless 2 USB
programmer and links to the fitting software used to interact with Phonak
and Signia hearing aids on Windows 11.

---

## 1. Noahlink Wireless 2

### What it is
The **Noahlink Wireless 2** (manufactured by HIMSA) is a USB dongle that
communicates with Bluetooth-capable hearing aids using the HIMSA wireless
fitting protocol.  It is the bridge between fitting software running on a
Windows PC and the hearing aids worn by the user.

### USB HID identifiers
| Property | Value  |
|---|---|
| Vendor ID | 0x0484 |
| Product ID  | 0x006E |

Verify on your machine with Python:

```python
import hid
for d in hid.enumerate():
    print(hex(d['vendor_id']), hex(d['product_id']), d['product_string'])
```

### Driver installation (Windows 11)
1. Plug the Noahlink Wireless 2 into a USB-A port.
2. Windows Update usually installs the HID driver automatically.
3. If not, download the HIMSA Noahlink Wireless software from
   <https://www.himsa.com/noahlink-wireless/> and run the installer.
4. Confirm the device appears in **Device Manager → Human Interface Devices**
   as *Noahlink Wireless 2*.

### Python `hid` library access (Windows)
The `hid` PyPI package (wraps `hidapi`) requires no additional drivers on
Windows beyond the standard HID stack.

```
pip install hid
```

---

## 2. Phonak Naída M70-SP — Fitting Software

| Item | Detail |
|---|---|
| Platform | Marvel (M-series) |
| Form factor | Size 13 BTE (Behind-the-Ear) |
| Connectivity | Bluetooth Classic (A2DP / HFP) |
| Fitting tool | **Phonak Target** |
| Download | Requires a licensed hearing care professional login at <https://www.phonak.com/professionals> |

### Pairing for audio streaming (Windows 11)
1. Open **Settings → Bluetooth & devices → Add device → Bluetooth**.
2. Put the Naída M70-SP into pairing mode (hold both buttons for 3 s; LED
   flashes rapidly).
3. Select the device from the list; accept the pairing request.
4. Once paired, the aid appears as a standard Windows audio output device.
5. Set `OUTPUT_DEVICE_INDEX` in `dsp/config.py` to the device's PyAudio index
   (use `python -m stream.bluetooth_output --list` to find it).

---

## 3. Signia Insio 7AX — Fitting Software

| Item | Detail |
|---|---|
| Platform | AX (Augmented Xperience) |
| Form factor | ITC custom mould (In-The-Canal) |
| Connectivity | Made-for-iPhone (MFi) Bluetooth LE |
| Fitting tool | **Connexx** (by Signia / WS Audiology) |
| Download | Requires a licensed hearing care professional login at <https://www.signia-pro.com> |

### Windows streaming caveat
The Insio 7AX uses Apple's MFi Bluetooth LE stack, which is not natively
supported on Windows.  For Phase 1 of OpenHear:

- Connect the Insio 7AX to an iPhone using the **Signia app**.
- Use the iPhone as a Bluetooth relay (play audio on the iPhone, route to
  the aid via MFi).
- Share iPhone audio to the Windows PC via a virtual audio cable solution
  (e.g. VB-Cable) or AirPlay if both devices are on the same network.

Native Windows MFi support is planned for a future phase.

---

## 4. Fitting Software Comparison

| Software | Manufacturer | Protocol | Open-source? |
|---|---|---|---|
| Phonak Target | Phonak | Noahlink / USB | No |
| Connexx | Signia (WSA) | Noahlink / USB | No |
| NOAH 4 | HIMSA | HIMSA protocol | No |

OpenHear does **not** depend on any of the above tools at runtime.  The
`core/read_fitting.py` module reads fitting data directly via USB HID and
currently exports the raw fitting payload to JSON; typed field parsing remains
pending confirmed HIMSA frame definitions.

---

## 5. Useful Links

- HIMSA (Noahlink Wireless 2 manufacturer): <https://www.himsa.com>
- Phonak professionals portal: <https://www.phonak.com/professionals>
- Signia professionals portal: <https://www.signia-pro.com>
- `hid` Python package: <https://pypi.org/project/hid/>
- PyAudio: <https://pypi.org/project/PyAudio/>

---

## 6. OpenHear Wristband prototype (micro:bit v2)

The first OpenHear wristband prototype uses a **BBC micro:bit v2**, two coin
vibration motors, two **2N2222** NPN transistors, two flyback diodes, and a
LiPo supply.  The Python side runs on Windows and sends a 3-byte BLE UART
packet to the micro:bit:

```
[sound_class_id, intensity_0_to_255, pattern_id]
```

### Pin map

| Function | micro:bit pin | Notes |
|---|---|---|
| Left motor driver | `P0` | Through 2N2222 transistor stage |
| Right motor driver | `P1` | Through 2N2222 transistor stage |
| Common ground | `GND` | Must be shared between micro:bit and motor supply |

### Motor driver wiring

Use a low-side transistor switch for each motor:

1. **Motor +** → battery **+**
2. **Motor -** → **collector** of a 2N2222
3. **Emitter** → common **GND**
4. micro:bit `P0` or `P1` → **1 kΩ resistor** → transistor **base**
5. Flyback diode across the motor:
   - diode **cathode** to motor/battery **+**
   - diode **anode** to the transistor collector / motor **-**
6. Tie the micro:bit ground and motor battery ground together

Do **not** drive the motors directly from the GPIO pins.  The transistor
stage is required because the micro:bit GPIO pins are current-limited.

### Exact motor driver wiring (tested values)

Use the same component values on both the left and right motor channels:

| Position | Exact part/value | Count | Notes |
|---|---|---:|---|
| Q1, Q2 | 2N2222A or PN2222A NPN transistor | 2 | TO-92 package is easiest on stripboard |
| R1, R2 | **1 kΩ**, 0.25 W, ±5% base resistor | 2 | Between `P0`/`P1` and the transistor base |
| R3, R4 | **10 kΩ**, 0.25 W, ±5% base pulldown | 2 | Base to GND so the motors stay off during boot |
| D1, D2 | **1N5819** Schottky flyback diode | 2 | Cathode to battery `+`, anode to collector / motor `-` |
| M1, M2 | 3 V coin vibration motor, ≤150 mA stall current | 2 | Keep the motor supply within the motor datasheet limit |

Per channel, wire it in this exact order:

1. micro:bit `P0`/`P1` → **1 kΩ** resistor → transistor **base**
2. transistor **base** → **10 kΩ** resistor → **GND**
3. transistor **emitter** → **GND**
4. motor **-** → transistor **collector**
5. motor **+** → motor battery **+**
6. **1N5819** across the motor, **cathode** to battery **+**, **anode** to collector
7. motor battery **-** tied to micro:bit **GND**

Practical limits for bench testing:

- Start at one motor only and confirm the transistor stays cool at a continuous
  `intensity=64` manual test.
- Keep first-power-on tests below **30 seconds** at a time until you have
  measured motor current and confirmed the wiring polarity.
- If the motor supply exceeds **3.7 V**, or a motor stalls above **150 mA**,
  do not use this transistor stage without redesigning the driver.

### Firmware flashing (Windows)

The simplest reliable Windows workflow is to flash from the official
micro:bit Python Editor or Mu Editor:

1. Install the **micro:bit Python Editor** or **Mu Editor** on Windows 11.
2. Connect the micro:bit v2 over USB and wait for the `MICROBIT` drive to
   appear in File Explorer.
3. Open `wristband/openhear_firmware.py` in the editor.
4. Click **Flash**. The editor packages the script into a MicroPython image
   and copies it to the board.
5. Wait for the yellow status LED on the micro:bit to stop flashing and for
   the board to reboot.
6. Confirm the display shows `H`; that is the wristband firmware idle marker.
7. If the board still runs an older image, press the reset button once and
   flash again with no other serial tools open.

If flashing fails on Windows:

- swap to a known data-capable USB cable,
- plug directly into the PC instead of a hub,
- close any serial terminal that may be holding the board,
- re-open the editor as Administrator once, then retry.

### Firmware

- Flash `wristband/openhear_firmware.py` to the micro:bit using a BLE-capable
  MicroPython build.
- `hardware/wristband/firmware.py` remains in the repo as a legacy mirror of
  the same seven-pattern prototype.
- The firmware listens for BLE UART packets and renders these patterns:
  - `voice` → both motors, gentle pulse
  - `doorbell` → two sharp pulses
  - `alarm` → rapid alternating left/right
  - `dog` → right-only pulse
  - `traffic` → left-only pulse
  - `media` → slow both-motor pulse
  - `silence` → no output

### Windows runtime

Use the integrated wristband runtime:

```bash
python -m stream.wristband_runtime --audiogram PATIENT.json --manual-sound alarm
python -m stream.wristband_runtime --audiogram PATIENT.json --model yamnet.tflite --labels stream/data/yamnet_class_map.csv
```

The runtime:

1. loads the patient's audiogram,
2. classifies sound windows into the OpenHear wristband classes,
3. scales the haptic intensity from the audiogram thresholds, and
4. sends the packet over BLE to the micro:bit advertising as `OpenHear`.

### Windows BLE debugging checklist

If the micro:bit does not appear or connect on Windows:

1. Confirm the firmware is running: the micro:bit should boot to `H`.
2. Make sure no other host is already connected to the micro:bit over BLE.
3. In **Settings → Bluetooth & devices**, remove any stale `OpenHear` pairing,
   then toggle Bluetooth off and back on.
4. Verify Windows can see the advert with Bleak:

   ```powershell
   py -c "import asyncio; from bleak import BleakScanner; print([(d.name, d.address) for d in asyncio.run(BleakScanner.discover(timeout=8.0)) if d.name])"
   ```

5. If `OpenHear` is missing, power-cycle the micro:bit and rerun the scan.
6. If `OpenHear` is present but the runtime still fails, increase the scan
   timeout:

   ```powershell
   py -m stream.wristband_runtime --audiogram PATIENT.json --manual-sound alarm --scan-timeout 15
   ```

7. If Bleak raises a Windows backend error, confirm you are using a normal
   64-bit Python build and that Windows has Bluetooth permission enabled for
   desktop apps.

### Experimental continuous texture: calibration required

`stream.crowd_arousal.CrowdArousalEstimator` describes recorded audio, not
emotion or crowd identity. Its compatibility names `arousal` and `tension`
mean **log RMS level** and **smoothed spectral-shape change**. Microphone gain,
distance, automatic gain control and compression all matter. The onset rate
counts envelope-rise detections, not necessarily distinct real-world events,
and remains diagnostic rather than driving a motor.

Frames must be real, finite, one-dimensional and exactly the configured size.
Frames at or below `silence_rms` (default **0.0001 RMS** in normalised audio)
immediately clear spectral-change state and map to zero intensity. Zero
arousal is always muted; active texture retains the provisional 40–160
intensity and 0.5–12 Hz ranges. These are engineering defaults, **not measured
comfort limits or universal perceptual thresholds**.

For continuous playback use `stream.haptic_playback.HapticPlayback`, not a new
one-second `HapticPrimitive.to_events()` schedule for every audio frame.
Update its texture from the estimator, submit alerts to the same instance,
and send only its polled events through a single serialised transport writer.
Its phase persists across texture updates; alert priority protects the entire
alert, including the gaps between alert pulses, from texture writes. The
intensity ceiling alone provides no priority guarantee.

Audio callbacks and playback must share one monotonic millisecond clock and
serialise access. Poll substantially faster than the shortest pulse: the
12 Hz/0.1-duty endpoint is only about **8.3 ms on**, so a 46 ms audio callback
is not a playback clock. Late polls skip obsolete edges instead of replaying
a backlog; this prevents stale output but cannot recover missed pulses.
Send the events returned by `stop(now_ms)` before disconnecting. Transport
failures, process stalls and physical motor shutoff still require device-side
handling; this host library is not a safety-certified alert system.

**Integration status:** this is an opt-in host-side API, not automatically
enabled by the Windows classifier runtime. The seven-pattern prototype
firmware above does not implement primitive pattern IDs 10–12 and falls back
to silence for unknown patterns. Its blocking pattern handlers also cannot
guarantee immediate preemption. Use primitive-capable, interruptible firmware
before attempting continuous playback; host scheduling tests do not establish
hardware compatibility.

Before making claims about the resulting sensations:

1. **Record the setup:** motor/driver model, supply voltage, firmware revision,
   mounting/strap, sample rate/frame size, microphone gain and AGC settings.
   Follow the electrical and short-duration bench limits above.
2. **Calibrate the input gate:** capture microphone background noise with fixed
   gain, choose `silence_rms` above that floor, and verify quiet target sounds
   are not inadvertently removed. Check silence transitions, steady tones,
   stationary noise, gain steps and sustained rises. Do not interpret digital
   RMS as calibrated sound-pressure level.
3. **Measure actual output:** verify centre routing and motor-off packets, then
   measure pulse timing, duty cycle and transport jitter across the proposed
   range. Test repeated frame updates without phase resets. Confirm missed
   deadlines do not produce queued bursts.
4. **Verify preemption on-device:** interrupt active texture with an alert,
   update/mute texture during the alert, and confirm no texture packet ends
   the alert early. Check expiry, stop, disconnect and device watchdog
   behaviour. Record observed latency rather than promising immediacy.
5. **Evaluate comfort and distinguishability with consenting wearers:** start
   low, provide an immediate stop control, and stop for discomfort. Compare
   level changes separately from texture changes and record suitable ranges;
   do not label responses as joy, anger, psychological tension or excitement.

Physical bench measurements and wearer calibration have **not** been performed
for these defaults. Keep them experimental until those results are available.

---

## 7. OpenHear aids-free wristband v1 DIY prototype

The v1 wristband assets live under [`hardware/wristband/`](hardware/wristband/)
and are the first buildable DIY step toward the north-star described in
[`docs/AIDS_FREE_ARCHITECTURE.md`](docs/AIDS_FREE_ARCHITECTURE.md). The design is
Burgess Principle aligned: no device in/on the ear, no cloud dependency, and no
phone in the acoustic-to-skin path.

Key files:

- CAD: [`hardware/wristband/cad/parametric_wristband_v1.scad`](hardware/wristband/cad/parametric_wristband_v1.scad)
- STL export helper: [`hardware/wristband/cad/generate_stl.sh`](hardware/wristband/cad/generate_stl.sh)
- KiCad v8 reference: [`hardware/wristband/kicad/`](hardware/wristband/kicad/)
- BOM: [`hardware/wristband/BOM.csv`](hardware/wristband/BOM.csv)
- Assembly guide: [`hardware/wristband/assembly_v1.md`](hardware/wristband/assembly_v1.md)
- Haptic mapper: [`hardware/wristband/firmware/haptic_mapper.py`](hardware/wristband/firmware/haptic_mapper.py)
- v1 firmware reference: [`hardware/wristband/firmware/openhear_firmware_v1.py`](hardware/wristband/firmware/openhear_firmware_v1.py)
- Power and thermal budget: [`hardware/wristband/power_budget_v1.md`](hardware/wristband/power_budget_v1.md)

The v0 micro:bit wristband remains supported through the v1 firmware packet codec
and haptic mapper compatibility shim, so existing users can keep the 3-byte BLE
UART flow while migrating to denser actuator hardware.

Regulatory note: this is a DIY research sensory-substitution prototype, not a
certified hearing aid or medical device. A clinical product would require a formal
safety file, usability engineering, biocompatibility evidence, and likely a Class
IIa-style route for an aids-free sensory substitution device.

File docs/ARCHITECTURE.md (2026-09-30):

# OpenHear Architecture

High-level map of the codebase.  Read this first if you want to know
*where* something lives; for *why* each stage exists see
`docs/TUNING_GUIDE.md`.

```
openhear/
├── audiogram/   ← Read, write, compare, visualise user audiograms.
│                  Canonical dataclass in audiogram/audiogram.py.
│
├── dsp/         ← Real-time DSP stages: noise reduction, WDRC
│                  compression, voice clarity, feedback cancellation,
│                  own-voice bypass, biquad filter bank, beamforming,
│                  audiogram → prescription, bone-conduction retarget
│                  (dsp/bone_conduction.py), runtime metrics.
│                  Entry point: python -m dsp.pipeline
│
├── stream/      ← Audio I/O and transport: Bluetooth output, virtual
│                  audio cable detection, round-trip latency test,
│                  raw/processed recorder, Phase 2/3 local training
│                  telemetry for wristband adaptation.
│
├── core/        ← Noahlink Wireless 2 bridge: HID wrapper
│                  (core/noahlink.py), framing parser (core/protocol.py),
│                  fitting dataclasses (core/fitting_data.py), read /
│                  write / backup CLIs.  See docs/PROTOCOL_NOTES.md.
│
├── hardware/    ← Out-of-tree open hearing-aid hardware: Tympan SDK
│                  integration, shell manufacturing notes, safety docs,
│                  Phase 5 sovereign-device bundle generation.
│
├── modules/optional/oral_appliance/  ← FTO hold. No CAD. See docs/FTO_SONITUS.md.
│
├── learn/       ← Listener preference capture, adaptive tuning,
│                  JSONL learning-state persistence, and saved
│                  per-environment profiles.
│
├── voice/       ← Legacy voice-reference / analysis helpers.
├── wristband/   ← Prototype haptic wristband transport.
├── examples/    ← Sample config, sample audiogram, offline demo.
└── tests/       ← pytest suite — 500+ tests, no real hardware needed.
```

## Data flow (live-fitting mode)

```
microphone
   |
   v
┌─────────────────────┐
│  stream.recorder     │─── optional raw.wav
└─────────────────────┘
           v
┌─────────────────────────────────────────────┐
│  dsp.pipeline                                │
│    SpectralSubtractor  → WDRCompressor       │
│    → VoiceClarityEnhancer                    │
│    → FeedbackCanceller → OwnVoiceBypass      │
└─────────────────────────────────────────────┘
           v processed audio
┌─────────────────────┐
│  stream.bluetooth    │──→ paired hearing aid (A2DP / MFi)
└─────────────────────┘
```

The DSP chain is driven by a user `config.yaml` parsed by
`dsp.user_config` against `dsp/config.schema.json`.  An
`Audiogram` dataclass flows through `dsp.audiogram_profile.prescribe()`
to produce per-band gains and compression ratios.  Bone-conduction
output is an optional retarget of that table
(`dsp.bone_conduction.prescribe_bc`); it is not a second pipeline.

## Data flow (fitting read / write)

```
core.noahlink.NoahlinkDevice
     │ send GET_FITTING frame
     v
core.protocol.decode_session
     │ produces ParsedFrame objects
     v
core.fitting_data.FittingSession
     │
     ├──→ core.backup.write_backup  (safety net)
     │
     └──→ core.write_fitting.write_safe_parameters
               (allow-list gated, transmit=True not yet implemented)
```

## Stability guarantees

* Public API surface is the `Audiogram`, `FittingSession`,
  `DeviceInfo`, `GainTable`, `CompressionProfile`, `MPOProfile`,
  `ProgrammeSlot`, `MetricsLogger`, `BluetoothAudioOutput`,
  `NoahlinkDevice`, `BoneConductionPrescription`, and the CLI entry
  points registered in `pyproject.toml`.
* Anything in an internal `_helper` module or named with a leading
  underscore may change without notice.

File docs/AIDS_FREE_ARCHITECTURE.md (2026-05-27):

# OpenHear Aids-Free Architecture

### A sovereign somatosensory hearing system. No hearing aid. No behind-the-ear receiver. No bone conduction implant. No ear canal device of any kind.

> *"The wristband — or a next-generation version of it — IS the complete hearing system."*

This document is the technical architecture for the standalone configuration of OpenHear: the version of the system in which **nothing is worn at the ear**. Sound is captured at the wrist, classified by edge AI, weighted against the user's audiogram, and rendered to the wearer as a high-resolution multi-frequency haptic field on the skin. The brain — through documented somatosensory plasticity — learns to read that field as auditory information.

This is not amplification. This is not bone conduction. This is not a cochlear implant. It is **direct sensory substitution**: sound delivered to the somatosensory cortex through the skin, and remapped over time by the wearer's own neuroplasticity into a usable representation of the acoustic world.

Audience: open-source firmware, DSP, ML, RTL, mechanical, clinical and HCI contributors who want to build this. The level of detail below is intended to be sufficient to begin contributing modules immediately.

---

## 0. Design principles

1. **No device in or on the ear.** The wrist is the entire system.
2. **Skin is the transducer.** Mechanoreceptors in glabrous and hairy skin are the receivers.
3. **Brain is the codec.** Adaptation, not perfect signal reconstruction, is the design target.
4. **Sub-5 ms end-to-end.** From acoustic event to first haptic edge on the skin.
5. **Sovereign at every layer.** Open silicon, open firmware, open DSP, open models, open data formats, open clinical protocols. The user owns the audiogram, the haptic preference profile, the trained personal model, and the neural-adaptation telemetry.
6. **Superior, not equivalent.** The target is not to imitate biological hearing. It is to exceed it — 360° + vertical spatial awareness, infrasonic and ultrasonic perception, and contextual classification that air-conduction physiology cannot perform.

---

## 1. System overview

```
                     ┌──────────────────────────────────────────────────────┐
                     │                  OpenHear Wristband                  │
                     │                                                      │
World ── acoustic ──▶│  Mic Array (8–16 MEMS, 20 Hz – 96 kHz, beamformable) │
                     │            │                                         │
                     │            ▼                                         │
                     │  Front-end DSP  (AGC, AEC, beamforming, VAD)         │
                     │            │                                         │
                     │            ▼                                         │
                     │  Hearing NPU  (classification, source separation,    │
                     │                audiogram-weighted band synthesis)    │
                     │            │                                         │
                     │            ▼                                         │
                     │  Haptic Renderer (frequency→position, intensity,     │
                     │                   spatial, temporal pattern)         │
                     │            │                                         │
                     │            ▼                                         │
                     │  Multi-Motor Haptic Array  (32–128 actuators)        │
                     │            │                                         │
                     └────────────┼─────────────────────────────────────────┘
                                  ▼
                       Skin → mechanoreceptors → somatosensory cortex
                                  ▼
                       (with training) auditory cortex remap
```

There is no Bluetooth-to-ear leg. There is no receiver. The chain ends on the skin.

A separate, optional, **companion** Bluetooth link exists for: (a) phone-based UI for configuring the personal model, (b) export of the user's data, and (c) interop with the existing OpenHear DSP pipeline for users running both modes during transition.

---

## 2. Skin as the transducer — what the physiology actually allows

### 2.1 Mechanoreceptor classes used

| Receptor | Sensitive band | Spatial acuity (wrist) | Role in OpenHear |
|---|---|---|---|
| Pacinian (PC) | 40 – 800 Hz, peak ~250 Hz | low (~10 mm) | mid/high frequency carrier; transient detection |
| Meissner (RA1) | 5 – 50 Hz | medium (~3 mm) | onset/offset; rhythm; envelope |
| Merkel (SA1) | 0.4 – 8 Hz | high (~1 mm) | spatial pattern; static intensity |
| Ruffini (SA2)  | 0.4 – 100 Hz | low | skin stretch; directional cues |

The usable haptic frequency window at the wrist is approximately **5 Hz – 1 kHz** at the body surface. Audio frequencies above this are not represented as raw vibration — they are **encoded** into spatial position, motor identity, and temporal pattern across the array. This is the central insight: we do not transmit a 20 kHz waveform to skin; we transmit a 20 kHz *symbol*.

### 2.2 Spatial resolution target

Two-point discrimination on the volar wrist is ~25–35 mm; on the dorsal wrist ~40 mm; on the fingertips ~2 mm. We target a wrist actuator pitch of **8–12 mm centre-to-centre**, deliberately tighter than two-point discrimination, to exploit *funnelling* and *apparent motion* illusions and yield a perceived spatial resolution finer than the physical receptor field.

- **Minimum viable**: 24 actuators in a single ring (Neosensory-class density).
- **Target v1**: 64 actuators in a 4-ring × 16-column lattice covering the full wrist circumference.
- **Aspirational v2**: 128 actuators extending up the forearm 60–80 mm, enabling a 2D haptic "screen".

### 2.3 Frequency-to-skin mapping

Audible spectrum is partitioned into **N bark-like critical bands** (default N=24 to match cochlear bands). Each band is assigned a triple `(motor_index, drive_freq_Hz, intensity_curve)`:

- `motor_index` — circumferential position; low audio bands → ulnar side, high audio bands → radial side, with the user's audiogram skewing weight toward bands they cannot hear acoustically.
- `drive_freq_Hz` — the actual mechanical frequency the motor outputs, chosen from the receptor-friendly 20–600 Hz window. Different audio bands are distinguished by motor *position* and *drive pattern*, not by drive frequency alone.
- `intensity_curve` — per-user perceptual mapping derived from a calibration session; replaces the audiologist's gain table.

### 2.4 Spatial cues — direction, elevation and distance

- **Azimuth (horizontal direction)**: derived from the wrist mic-array beamformer; encoded as the angular *origin* of a haptic pattern that propagates around the wrist (apparent motion).
- **Elevation**: encoded by *ring index* on the lattice (proximal ring = below, distal ring = above).
- **Distance**: encoded by intensity envelope and decay rate.
- **>360° awareness**: because elevation is independent of azimuth, the wristband can represent the full sphere around the user, including overhead — which biological hearing handles poorly.

---

## 3. Neural adaptation — why this works

### 3.1 Evidence base

- Bach-y-Rita's *tactile-visual sensory substitution* (TVSS, 1969) established that the brain remaps tactile input from a 20×20 grid into a usable visual percept after training.
- Eagleman & Novich's VEST/Neosensory work demonstrates auditory→tactile substitution producing word recognition in deaf adults after a few weeks of daily wear.
- fMRI studies of long-term Neosensory wearers show recruitment of auditory cortex by tactile stimuli — the cortical remap is real and measurable.
- Cochlear-implant research shows central plasticity timelines of weeks to months, even for radically non-natural input codes.
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

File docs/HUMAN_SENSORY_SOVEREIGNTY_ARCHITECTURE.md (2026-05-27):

# OpenHear Human Sensory Sovereignty Architecture

### Your senses. Your data. Your world.

This document is the full technical architecture for OpenHear as a human sensory sovereignty platform. It is written so an open-source engineering community can begin contributing immediately across all nine pillars, from the current sovereign DSP pipeline to the future wrist-native, aids-free sensory system.

## The nine pillars

1. The OpenHear Wristband — active environmental intelligence
2. Aids-free architecture — the wristband as the complete hearing system
3. Peak hearing for all users
4. Selective acoustic sovereignty
5. Therapeutic frequency delivery — 30 to 300 Hz
6. iOS and Android native integration
7. Emotional and cognitive acoustic intelligence
8. Social acoustic layer
9. Beyond biological hearing

---

## 0. Non-negotiables
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

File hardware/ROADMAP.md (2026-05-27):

# Hardware Roadmap

From documentation to sovereign device. Five phases, each building on the last.

---

## Phase 1: Documentation (Current)

**Status:** In progress

Lay the groundwork. Every decision documented. Every component specified. Every safety measure designed before a single wire is soldered.

- [x] Bill of materials with three build tiers
- [x] Tympan bridge script (audiogram JSON → Arduino sketch)
- [x] Safety module with MPO limiter design, calibration procedure, and risk register
- [x] Assembly guide for all three tiers
- [x] 3D printing guide for custom ear moulds
- [x] Parametric mould template documentation
- [ ] Community review of safety module
- [ ] Audiologist review of MPO calculations
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

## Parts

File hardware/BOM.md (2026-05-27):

# Bill of Materials

All prices in GBP (£). Prices are approximate and may vary by supplier and region. See [sourcing notes](#sourcing-notes) at the bottom for international alternatives.

---

## Tier 1: Explorer (~£300)

Everything you need to hear your audiogram-tuned audio through headphones. No soldering required.

| Component | Part | Supplier | Approx Cost | Notes |
|---|---|---|---|---|
| Dev board | [Tympan Rev F](https://shop.tympan.org/) | shop.tympan.org | £250 | Open-source hearing aid dev board. Teensy 4.1 based, 600 MHz ARM Cortex-M7. [Datasheet](https://github.com/Tympan/Docs/wiki) |
| Headphones | Any wired over-ear headphones, 32Ω impedance | Amazon / local | £30 | 3.5mm jack. Over-ear recommended for comfort during testing. Avoid noise-cancelling models — they add latency |
| Microphone | 3.5mm lavalier / lapel microphone | Amazon / local | £10 | Omnidirectional. Clip to collar for voice pickup during testing |
| Cable | USB-C to USB-A cable | Amazon / local | £5 | For programming the Tympan via Arduino IDE. At least 1m length recommended |
| | | | **~£295** | |

---

## Tier 2: Builder (~£450)

Adds BTE earpieces, balanced armature receivers, custom moulds, and the mandatory MPO limiter circuit. This tier produces a wearable hearing aid.

| Component | Part | Supplier | Approx Cost | Notes |
|---|---|---|---|---|
| *All Tier 1 components above* | | | £295 | Headphones become optional once earpieces are built |
| Earpiece kit | [Tympan Earpiece Kit](https://shop.tympan.org/) | shop.tympan.org | £80 | Includes L+R BTE housings with dual MEMS microphones. [Docs](https://github.com/Tympan/Docs/wiki/Tympan-Earpieces) |
| Receivers | Knowles ED-series or WBFK-series balanced armature | [DigiKey](https://www.digikey.co.uk/) / [Mouser](https://www.mouser.co.uk/) | £20 | ED-29689 for mild-moderate loss. WBFK-30019 for severe-profound. See [receiver selection](#receiver-selection) |
| Ear moulds | 3D printed custom moulds | Self-made (resin or FDM) | £30 | Material cost only. See [shell/ module](shell/README.md) for printing guide |
| Impression kit | Two-part medical silicone ear impression kit | Amazon | £15 | Food-grade or medical-grade silicone. Includes mixing cups and syringe. See [shell/ safety warnings](shell/README.md#taking-ear-impressions) |
| Battery | 3.7V LiPo 500mAh | Amazon / Pimoroni | £10 | JST-PH 2.0mm connector for Tympan. [Datasheet](https://www.olimex.com/Products/Power/BATTERY-LIPO500mAh/) — check connector polarity before connecting |
| Misc | Wire (30 AWG silicone), JST connectors, heat shrink | Amazon / local | £15 | Silicone wire recommended for flexibility. Include spare connectors |
| | | | **~£465** | Subtract £30 if headphones not needed |

---

## Tier 3: Sovereign (~£550)

Adds precision printing capability, calibration equipment, and hardware limiter components for a fully self-contained build.

| Component | Part | Supplier | Approx Cost | Notes |
|---|---|---|---|---|
| *All Tier 2 components above* | | | £435 | Without headphones |
| 3D printer | [Elegoo Mars 4](https://www.elegoo.com/products/elegoo-mars-4) | Elegoo / Amazon | £200 | MSLA resin printer. 0.05mm layer height for smooth ear moulds. Alternative: any resin printer with ≤0.05mm resolution |
| Resin | Biocompatible resin (Class I) | Elegoo / FormLabs / Amazon | £40 | Must be rated for skin contact. [Elegoo Bio Resin datasheet](https://www.elegoo.com/products/elegoo-bio-photopolymer-resin). UV cure fully before skin contact |
| Calibration mic | [Dayton Audio iMM-6](https://www.daytonaudio.com/product/1117/imm-6-idevice-calibrated-measurement-microphone) | Parts Express / Amazon | £20 | Calibrated measurement microphone. Comes with individual calibration file. Essential for MPO verification |
| MPO limiter | Zener diodes, resistors, perfboard | DigiKey / Mouser / local | £5 | See [safety module](safety/README.md) for circuit design and component values |
| | | | **~£700** | Or **~£500** if you already own a resin printer |

> **Note:** Tier 3 cost includes a resin printer, which is a one-time purchase. If you already own one, the marginal cost is around £500 total for a complete binaural system. Many makerspaces and libraries have resin printers available for free or low cost.

---

## Receiver Selection

The balanced armature receiver converts electrical signal to sound inside the ear canal. Choosing the right one matters.

| Hearing Loss | Recommended Receiver | Max Output | Notes |
|---|---|---|---|
| Mild (26–40 dB) | Knowles ED-29689 | ~108 dB SPL | Lower power, longer battery life. [Datasheet](https://www.knowles.com/docs/default-source/default-document-library/ed-29689.pdf) |
| Moderate (41–55 dB) | Knowles ED-29689 | ~108 dB SPL | Same receiver, higher gain in DSP |
| Moderately-severe (56–70 dB) | Knowles WBFK-30019 | ~114 dB SPL | Higher output capability. [Datasheet](https://www.knowles.com/docs/default-source/default-document-library/wbfk-30019.pdf) |
| Severe (71–90 dB) | Knowles WBFK-30019 | ~114 dB SPL | Use with hardware MPO limiter (mandatory) |
| Profound (91+ dB) | Knowles WBFK-30095 | ~120 dB SPL | Maximum output. Hardware MPO limiter is **critical**. [Datasheet](https://www.knowles.com/docs/default-source/default-document-library/wbfk-30095.pdf) |

**Critical components (do not substitute):**
- Tympan Rev F — the entire software pipeline depends on this board
- Knowles balanced armature receivers — output characteristics are calibrated to these specific models
- Biocompatible resin for anything that contacts skin or ear canal

**Substitutable components:**
- Headphones (any wired 32Ω over-ear)
- Lavalier microphone (any 3.5mm omnidirectional)
- USB cable (any USB-C cable)
- Wire and connectors (any 30 AWG silicone wire)
- Soldering iron (any temperature-controlled iron)
- 3D printer (any resin printer with ≤0.05mm layer resolution)

---

## Sourcing Notes

### UK Suppliers (Primary)
- **Tympan:** [shop.tympan.org](https://shop.tympan.org/) — ships internationally
- **Knowles receivers:** [DigiKey UK](https://www.digikey.co.uk/), [Mouser UK](https://www.mouser.co.uk/), [Farnell](https://uk.farnell.com/)
- **General electronics:** [Pimoroni](https://shop.pimoroni.com/), [The Pi Hut](https://thepihut.com/)

### US Suppliers
- **Knowles receivers:** [DigiKey](https://www.digikey.com/), [Mouser](https://www.mouser.com/)
- **Calibration mic:** [Parts Express](https://www.parts-express.com/)
- **3D printing supplies:** [MatterHackers](https://www.matterhackers.com/)

### EU Suppliers
- **Knowles receivers:** [DigiKey EU](https://www.digikey.eu/), [Mouser EU](https://www.mouser.eu/)
- **Electronics:** [Reichelt](https://www.reichelt.de/), [Conrad](https://www.conrad.com/)

### Rest of World
- **Tympan ships internationally.** Check customs and import duties for your country.
- **Knowles receivers** are available from DigiKey and Mouser in most countries.
- **AliExpress** carries compatible LiPo batteries, wire, and connectors at lower prices. Verify specifications before purchasing — counterfeit components are common.

---

## Datasheet Links (Quick Reference)

| Component | Datasheet |
|---|---|
| Tympan Rev F | [Tympan Wiki](https://github.com/Tympan/Docs/wiki) |
| Teensy 4.1 (Tympan CPU) | [PJRC Teensy 4.1](https://www.pjrc.com/store/teensy41.html) |
| Knowles ED-29689 | [ED-29689 PDF](https://www.knowles.com/docs/default-source/default-document-library/ed-29689.pdf) |
| Knowles WBFK-30019 | [WBFK-30019 PDF](https://www.knowles.com/docs/default-source/default-document-library/wbfk-30019.pdf) |
| Knowles WBFK-30095 | [WBFK-30095 PDF](https://www.knowles.com/docs/default-source/default-document-library/wbfk-30095.pdf) |
| Dayton Audio iMM-6 | [iMM-6 Product Page](https://www.daytonaudio.com/product/1117/imm-6-idevice-calibrated-measurement-microphone) |

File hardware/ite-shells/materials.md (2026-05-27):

# Materials Guide — ITE Shell Resins, Coatings & Pigments

> Choose what touches your body. This is sovereign material selection.

This guide covers every material you need to build a comfortable, durable, skin-like ITE shell. All recommendations are current as of 2025–2026 and prioritise biocompatibility, skin feel, and availability to makers.

---

## Biocompatible Resin Comparison

### Rigid Resins (Shell Body)

These resins form the structural shell. They are hard, dimensionally stable, and suitable for housing electronics.

| Resin | Manufacturer | Biocompatibility | Shore Hardness | Tensile Strength | Elongation | UV Stable | Price (approx.) | Notes |
|---|---|---|---|---|---|---|---|---|
| **BioMed Clear** | Formlabs | ISO 10993-5, 10993-10 (cytotoxicity, irritation) | 85D | 51 MPa | 6% | Good | £200/L | Gold standard for hearing aid shells. Optically clear, excellent surface finish. Requires Form 3B+/4B printer |
| **BioMed Durable** | Formlabs | ISO 10993-5, 10993-10 | 78D | 32 MPa | 35% | Good | £200/L | More impact-resistant than BioMed Clear. Slight flexibility reduces cracking. Requires Form 3B+/4B |
| **OTO-A1 Shell** | 3Dresyns | ISO 10993-5 | 82D | 45 MPa | 8% | Moderate | €120/500mL | Purpose-designed for hearing aid shells. Works with open resin printers (Elegoo, Anycubic) |
| **OTO-C1 Clear** | 3Dresyns | ISO 10993-5 | 80D | 40 MPa | 10% | Good | €110/500mL | Clear variant of the OTO series. Good for translucent shells |
| **luxaprint shell** | DETAX | ISO 10993-5, ISO 10993-10, Class IIa | 84D | 55 MPa | 5% | Excellent | €180/1kg | Industry-standard hearing aid shell resin. Exceptional detail and dimensional stability |
| **Freeprint shell** | DETAX | ISO 10993-5, ISO 10993-10 | 82D | 50 MPa | 7% | Excellent | €160/1kg | Slightly more flexible variant. Lower viscosity — easier printing |
| **Bio-Med Clear** | Liqcreate | ISO 10993-5, USP Class VI | 82D | 50 MPa | 5% | Good | €90/1kg | Excellent value. Works with most open MSLA printers. Good dimensional accuracy |
| **Bio Resin** | Elegoo | Class I biocompatible, basic skin contact | 80D | 40 MPa | 6% | Moderate | £40/500mL | Budget option. Suitable for prototyping and iteration. Fully cure before skin contact |

> **Recommendation for most makers:** Start with **Liqcreate Bio-Med Clear** or **Elegoo Bio Resin** for prototyping and fit iteration. Move to **3Dresyns OTO-A1** or **DETAX Freeprint shell** for final-quality shells. Use **Formlabs BioMed Clear** only if you own a Form 3B+/4B.

### Flexible / Skin-Like Resins (Canal Tips, Soft Inserts)

These resins produce soft, flexible parts. Use them for canal tips, comfort liners, or full soft-shell designs that feel like skin rather than hard plastic.

| Resin | Manufacturer | Biocompatibility | Shore Hardness | Elongation | Tear Strength | Feel | Price (approx.) | Notes |
|---|---|---|---|---|---|---|---|---|
| **BioMed Flex 80A** | Formlabs | ISO 10993-5, 10993-10 | 80A | 110% | 25 kN/m | Firm rubber | £200/L | Similar feel to a hearing aid dome. Semi-flexible. Requires Form 3B+/4B |
| **Elastic 50A** | Formlabs | ISO 10993-5, 10993-10 | 50A | 160% | 19 kN/m | Soft silicone-like | £200/L | Very soft. Closest to skin feel. Excellent for canal tips. Requires Form 3B+/4B |
| **Flexible 80A** | Formlabs | ISO 10993-5, 10993-10 | 80A | 120% | 24 kN/m | Firm rubber | £180/L | Non-BioMed version. Fine for prototyping, not for final ear canal use |
| **OTO-F1 Flex** | 3Dresyns | ISO 10993-5 | 60A | 200% | 20 kN/m | Soft, elastic | €140/500mL | Works on open printers. Best flexible option for non-Formlabs users |
| **Resione F69 Bio** | Resione | ISO 10993-5 | 50A–70A (tunable) | 250% | 18 kN/m | Very soft, skin-like | ~£50/500mL | Variable hardness by cure time. Budget-friendly. Available on AliExpress |
| **Siraya Tech Tenacious** | Siraya Tech | Basic biocompatible (skin contact after full cure) | 80A | 140% | 22 kN/m | Firm rubber | £50/500mL | Mix with rigid resin 20:80 for toughened shells. Full flexible at 100% |

> **Shore Hardness Guide for Context:**
>
> | Shore A Rating | Feels Like | Suitability |
> |---------------|-----------|-------------|
> | 30A–40A | Gummy bear, soft gel | Too soft for structural shells. Good for comfort pads |
> | 50A | Rubber band, pencil eraser | Excellent canal tip material. Skin-like softness |
> | 60A–70A | Shoe sole, firm rubber | Good balance of comfort and durability |
> | 80A | Car tyre, hard rubber | Semi-rigid. Good for full-shell flex builds |
> | 85D+ | Hard plastic | Structural shell material |

### Hybrid Approach (Recommended)

The best ITE shells combine rigid and flexible materials:

- **Rigid shell body** (85D resin) — houses electronics, provides structural integrity
- **Flexible canal tip** (50A–80A resin) — contacts ear canal, provides comfort and seal
- **Bonded interface** — the flexible tip is printed separately and bonded to the rigid shell with cyanoacrylate (super glue) or UV-cure adhesive

This mimics how professional hearing aid labs build shells: hard body, soft tip. The soft tip conforms slightly to your ear canal under body heat, creating a better seal and more comfortable fit.

### 2026 Material Updates

The following materials have emerged or been validated for hearing aid shell use since mid-2025:

| Resin | Manufacturer | Biocompatibility | Shore Hardness | Key Improvement | Price (approx.) | Notes |
|---|---|---|---|---|---|---|
| **BioMed Elastic 50A** | Formlabs | ISO 10993-5, 10993-10 | 50A | Skin-like softness for canal tips; improved tear resistance over Elastic 50A (2024 reformulation) | £210/L | Best-in-class soft canal tip material. Requires Form 3B+/4B |
| **Bio-Med Clear v2** | Liqcreate | ISO 10993-5, USP Class VI | 82D | Improved UV stability and reduced yellowing vs v1; lower viscosity for easier printing | €95/1kg | Excellent value. Works with most open MSLA printers |
| **luxaprint mould** | DETAX | ISO 10993-5, 10993-10, Class IIa | 65A | Purpose-designed for flexible ear moulds; better elongation than Freeprint | €190/1kg | For full-flex ITE shells or soft liners |

#### Pro10 HydraShield-Style Nano-Coating Recipe

For makers who want to achieve professional-grade sweat-proofing comparable to the coatings used on premium 2026 commercial aids (e.g., Phonak Lumity Life IP68 coating), the following DIY recipe approximates the performance:

**Materials:**
- NANOMYTE SR-500HP (fluorinated silane SAM) — primary omniphobic layer
- 99% IPA — surface preparation
- Plasma surface activator (optional — a handheld corona treater such as the Electro-Technic BD-20AC, ~£150, significantly improves coating adhesion)

**Procedure:**
1. Sand shell to 2000 grit, wet-sand final pass
2. Clean with 99% IPA, allow to dry completely (10 min)
3. *(Optional but recommended)* Pass corona treater over surface for 10 seconds per cm² — activates surface energy for better coating adhesion
4. Dip shell in NANOMYTE SR-500HP for 60 seconds
5. Remove slowly, drip-dry vertically for 2 minutes
6. Heat cure at 60°C for 30 minutes (domestic oven on lowest setting)
7. Allow to cool to room temperature
8. Apply second dip coat (repeat steps 4–7) for maximum durability

**Expected performance:**
- Water contact angle: >115° (superhydrophobic threshold)
- Oil/earwax contact angle: >95° (oleophobic)
- Durability: 12–18 months before reapplication needed
- Comparable to Phonak Life/Lumity IP68-rated nano-coating

See [sweatproof.md](sweatproof.md) for the combined microstructure + coating approach that pushes durability even further.

---

## Pigmentation — Skin-Tone Matching

Bare resin is typically clear, white, or translucent. For a natural appearance, ITE shells should be pigmented to match (or approximate) your skin tone.

### Methods

#### 1. Pre-Mix Pigment into Resin (Best Results)

Add pigment directly to the resin before printing. This produces uniform colour throughout the shell — no surface layer to chip or wear.

| Pigment Type | Supplier | Usage Rate | Notes |
|---|---|---|---|
| **Resin pigment paste (skin tones)** | Monocure3D, 3Dresyns | 0.5–2% by weight | Purpose-made for UV resins. Skin tone packs available |
| **Alcohol-based dye (skin tones)** | Smooth-On Silc Pig, custom cosmetic pigments | 0.1–0.5% by weight | Mix thoroughly. Test small batch first |
| **Mica powder (matte finishes)** | Hobbycraft, Amazon cosmetic suppliers | 1–3% by weight | Creates a matte, slightly pearlescent finish. Flesh-tone mica powders available |

**Recommended mix process:**

1. Weigh your resin in a clean mixing cup
2. Add pigment paste/powder at 1% by weight to start
3. Stir thoroughly for 2–3 minutes — no streaks should be visible
4. Print a small test piece and compare to your skin in natural light
5. Adjust pigment percentage up or down and repeat until satisfied
6. Once calibrated, record the exact ratio for future batches

> **Warning:** Adding too much pigment (>3%) can interfere with UV curing. The pigment absorbs UV light, so thicker layers may not cure fully. Increase exposure time by 10–20% when using pigmented resin and always verify cure quality.

#### 2. Post-Print Surface Colouring

If you prefer to print in uncoloured resin, you can apply colour after printing.

| Method | Product | Notes |
|---|---|---|
| **Airbrush with skin-tone paint** | Tamiya flat flesh, Vallejo skin tone set | Best control. Apply 2–3 thin coats. Seal with matte clear coat |
| **Spray paint** | Montana Gold flesh tones | Quick but less precise. Use in well-ventilated area |
| **Dip dye** | iDye Poly (for synthetics) | Immerse cured resin in hot dye bath. Results vary by resin |

#### 3. Matte Texturing (Skin-Like Surface)

A matte finish feels more natural against skin than a glossy surface. Hard, shiny plastic screams "medical device." Matte, soft-touch surfaces feel like skin.

| Technique | How | Result |
|---|-----|---|
| **Matte clear coat** | Spray matte lacquer (e.g., Tamiya TS-80 Flat Clear, Mr. Hobby Flat Clear) over pigmented shell | Removes shine, feels soft to touch |
| **Micro-sandblasting** | Blast cured shell with fine aluminium oxide media (120–220 grit) at low pressure | Uniform matte texture. Excellent skin-like feel |
| **Fine sanding** | Wet-sand with 1500–2000 grit, then do NOT polish — stop at matte | Simple, no equipment needed |
| **Textured print surface** | Add micro-texture to the STL (0.05–0.1mm bumps) in CAD before printing | Built-in matte texture. No post-processing needed |

> **Best combination for skin-like appearance:**
> Pre-mix flesh-tone pigment → print → sand to 1500 grit → apply matte clear coat → apply hydrophobic topcoat (see [sweat-proofing.md](sweat-proofing.md))

---

## Where to Buy

### UK Suppliers

| Material | Supplier | Link | Notes |
|---|---|---|---|
| Elegoo Bio Resin | Amazon UK / Elegoo | [elegoo.com](https://www.elegoo.com/) | Fast UK delivery |
| Liqcreate Bio-Med Clear | 3DJake UK | [3djake.uk](https://www.3djake.uk/) | Free shipping over £50 |
| Siraya Tech Tenacious | Amazon UK | [amazon.co.uk](https://www.amazon.co.uk/) | UK stock available |
| Monocure3D pigments | 3DFilaprint | [3dfilaprint.com](https://www.3dfilaprint.com/) | UK-based resin supplier |
| Matte clear coat (Tamiya TS-80) | Hobbycraft, Amazon UK | [hobbycraft.co.uk](https://www.hobbycraft.co.uk/) | Widely available |
| IPA (99%) | Amazon UK, Boots | — | Buy in 5L containers for economy |

### EU Suppliers

| Material | Supplier | Link | Notes |
|---|---|---|---|
| DETAX luxaprint / Freeprint | DETAX direct, dental supply | [detax.de](https://www.detax.de/) | Ships across EU. Also via dental distributors |
| 3Dresyns OTO series | 3Dresyns | [3dresyns.com](https://www.3dresyns.com/) | Spain-based. Ships EU-wide |
| Liqcreate Bio-Med Clear | 3DJake, iGo3D | [3djake.com](https://www.3djake.com/) | EU warehouses |
| Formlabs BioMed resins | Formlabs, 3D Hubs | [formlabs.com](https://www.formlabs.com/) | EU distributor network |

### US Suppliers

| Material | Supplier | Link | Notes |
|---|---|---|---|
| Formlabs BioMed Clear/Flex | Formlabs direct | [formlabs.com](https://www.formlabs.com/) | Direct US sales |
| Siraya Tech Tenacious | Amazon US, Siraya Tech | [siraya.tech](https://www.siraya.tech/) | US-based manufacturer |
| Elegoo Bio Resin | Amazon US, Elegoo | [elegoo.com](https://www.elegoo.com/) | US warehouse |
| Liqcreate Bio-Med Clear | MatterHackers | [matterhackers.com](https://www.matterhackers.com/) | US distributor |

---

## Biocompatibility Testing — Patch Test Protocol

Before wearing any printed shell in your ear for extended periods, perform this skin patch test:

1. **Print a small test disc** (10mm diameter × 2mm thick) using your chosen resin and exact print/cure settings
2. **Wash and cure** the disc using the same post-processing you will use for the final shell
3. **Tape the disc to the inside of your forearm** using medical tape (Micropore or similar)
4. **Wear for 24 hours**
5. **Remove and inspect:** Any redness, itching, swelling, or rash indicates a reaction
6. **If no reaction:** Repeat for 48 hours on a fresh skin area
7. **If still no reaction:** The resin is likely safe for your ear canal, but start with short wear sessions (1 hour, then 4 hours, then 8 hours)

> **If you experience any skin reaction, do not use that resin in your ear.** Try a different resin formulation and repeat the test. Some people are sensitive to specific photoinitiators or monomers. Switching resin brands usually resolves this.

---

## Material Safety

- **Uncured resin is toxic.** Always wear nitrile gloves when handling liquid resin or freshly printed parts. Avoid skin contact, inhalation, and eye contact.
- **IPA is flammable.** Use in a well-ventilated area away from heat sources. Store in sealed containers.
- **UV curing is essential.** A "biocompatible" resin is only biocompatible after full UV post-cure. Undercured resin leaches unreacted monomers that cause irritation.
- **Dust from sanding cured resin** is an inhalant hazard. Wet-sand whenever possible. Wear a dust mask (FFP2/N95 minimum) when dry sanding.
- **Dispose of resin waste responsibly.** Cure waste resin in sunlight before disposal. Do not pour liquid resin down drains.

---

*Next: [sweat-proofing.md](sweat-proofing.md) — making your shell truly moisture-proof.*

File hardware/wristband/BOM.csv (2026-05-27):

Part number | Description | Qty 24-actuator | Qty 64-actuator | Supplier | Unit price approx May 2026 GBP | Total 24 GBP | Total 64 GBP | Alternative | Notes
ESP32-S3-MINI-1-N8 | Wi-Fi/BLE 5 MCU module for companion link and scheduler | 1 | 1 | DigiKey/Mouser | 3.80 | 3.80 | 3.80 | RP2040 + MDBT50Q/nRF52840 | Radio is companion-only; local hearing path remains on-device
RP2040 | Deterministic dual-core MCU option for low-latency scheduler | 0 | 1 | DigiKey/Mouser | 0.95 | 0.00 | 0.95 | ESP32-S3 only | Use PIO/DMA for PDM and haptic timing
DRV2605LDGST | Haptic LRA/ERM driver with waveform engine | 8 | 16 | DigiKey/Mouser | 2.25 | 18.00 | 36.00 | TI DRV2625 or DA7280 | Direct channels reduce latency; muxed starter builds are cheaper
TCA9548APWR | 8-channel I2C mux for DRV2605L address fan-out | 1 | 2 | DigiKey/Mouser | 0.75 | 0.75 | 1.50 | LCSC TCA9548A module | Keep branch capacitance low
TDC TacHammer Haptuator | Wideband LRA actuator | 24 | 64 | Mouser/Tactile Labs | 3.20 | 76.80 | 204.80 | Precision Microdrives C10-100 or Jinlong LRA | Validate comfort before buying 64
SPH0645LM4H-B | MEMS I2S microphone | 8 | 8 | DigiKey/Mouser | 2.10 | 16.80 | 16.80 | SPH0644LM4H PDM | Use acoustic mesh and isolated ground return
BMI270 | 6-axis IMU for arm-pose compensation | 1 | 1 | DigiKey/Mouser/LCSC | 1.70 | 1.70 | 1.70 | BNO055 module | BNO055 is easier but larger and costlier
BQ24075RGTR | Li-Po charger and power-path management | 1 | 1 | DigiKey/Mouser | 2.60 | 2.60 | 2.60 | TP4056 module for bench-only | Use BQ24075 for wearable power-path safety
TPS62743DSSR | Low-quiescent 3.3 V buck regulator | 1 | 1 | DigiKey/Mouser | 1.90 | 1.90 | 1.90 | TPS62840 | Choose low-Iq regulator for 18-24 h target
2x 803040 Li-Po 800 mAh | Hot-swap battery cartridge cells | 2 | 2 | Adafruit/Pimoroni/Amazon UK | 6.50 | 13.00 | 13.00 | Protected 752540 cells | Use protected cells; never charge unattended during prototype
Qi receiver coil 5 V 1 A | Optional wireless charging receiver | 0 | 1 | LCSC/Amazon UK | 3.50 | 0.00 | 3.50 | USB-C charge only | Optional; isolate thermally from skin
USB-C 16-pin receptacle | Debug and charging connector | 1 | 1 | DigiKey/LCSC | 0.35 | 0.35 | 0.35 | Magnetic pogo dock | Seal with gasket or omit for Qi-only sealed builds
Medical silicone sheet/dip | User-facing overmold and gasket material | 1 | 1 | Smooth-On/specialist supplier | 18.00 | 18.00 | 18.00 | Dragon Skin 10 MED equivalent | Biocompatibility depends on exact cure and supplier documentation
IP67 acoustic membrane | Mic vent membrane patches | 8 | 8 | PUI/Gore reseller | 0.45 | 3.60 | 3.60 | PTFE vent dots | Protects MEMS ports from sweat ingress
M1.6 stainless screws | Enclosure fasteners | 12 | 16 | Accu/DigiKey | 0.08 | 0.96 | 1.28 | Heat-set inserts + TPU strap | No exposed sharp edges
Flex PCB fabrication | Polyimide actuator/mic flex tails | 1 | 1 | JLCPCB/PCBWay | 18.00 | 18.00 | 32.00 | Discrete silicone wire harness | Lead time and stack-up dominate risk
Resin/FDM printed enclosure | Parametric wrist shell and battery cartridge | 1 | 1 | DIY print | 8.00 | 8.00 | 10.00 | TPU strap + SLA hard shell | Use biocompatible resin or seal completely

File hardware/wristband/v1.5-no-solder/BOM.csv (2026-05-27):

Category | Part | Recommended 2026 example | Qty 24 | Qty 64 | Connector/no-solder detail | Supplier examples | Approx unit GBP May 2026 | Notes
MCU module | ESP32-S3 dev board | Seeed Studio XIAO ESP32S3 Sense or Adafruit Feather ESP32-S3 TFT | 1 | 1 | USB-C preassembled; castellated pins unused | Seeed/Adafruit/Pimoroni/DigiKey | 10-22 | Starter recommendation: XIAO ESP32S3 Sense for compact USB flashing and onboard mic camera disabled
MCU module | RP2040 dev board option | Adafruit Feather RP2040 USB-C or Pimoroni PGA2040 | 0 | 1 | USB-C preassembled; use STEMMA QT/JST where available | Adafruit/Pimoroni/DigiKey | 9-14 | Use for deterministic scheduler research; ESP32-S3 remains easiest beginner board
Haptic driver module | DRV2605L breakout | Adafruit DRV2605L Haptic Motor Controller STEMMA QT | 8 | 16 | JST-SH STEMMA QT I2C in/out plus screwless/JST actuator adapter | Adafruit/Pimoroni/DigiKey | 7-9 | One module can drive one LRA/ERM; duplicate addresses require mux branches
I2C mux module | TCA9548A breakout | Adafruit TCA9548A STEMMA QT multiplexer | 1 | 2 | JST-SH STEMMA QT | Adafruit/Pimoroni/DigiKey | 7-9 | Creates address-isolated DRV2605L banks without soldering
Actuator | Pre-wired LRA coin motor | Precision Microdrives 10 mm LRA with JST-PH/GH lead or Jinlong LRA with JST lead | 24 | 64 | Factory-crimped 2-pin JST lead | Precision Microdrives/Jinlong/AliExpress vetted sellers | 2.5-4.5 | Beginner-safe choice; tape label each connector A00-A23 or A00-A63 before inserting
Actuator premium | Pre-wired TacHammer class haptuator | Tactile Labs/Titan pre-wired TacHammer dev units | 0 | 64 | Factory lead to JST-GH adapter | Tactile Labs/Mouser where stocked | 8-15 | Research 64-actuator option; larger and higher current than LRA starter
Magnetic connector | 4/6/8-pin magnetic pogo pair | Adafruit magnetic pogo connector or 2.54 mm keyed magnetic pogo pair | 6 | 12 | Prewired pigtails or board-to-board pogo pair | Adafruit/Amazon/AliExpress | 2-6 | Use keyed polarity; mark gold-dot side as VBUS/3V3 side in assembly
JST cable | JST-SH 4-pin STEMMA QT cable | 50 mm and 100 mm Qwiic/STEMMA QT cables | 10 | 20 | Pre-crimped plug-to-plug | Adafruit/SparkFun/Pimoroni | 1-2 | I2C daisy-chain and mux branches
JST cable | JST-PH/GH 2-pin extension | 100 mm pre-crimped motor/battery extensions | 24 | 64 | Pre-crimped plug-to-socket | Adafruit/SparkFun/Amazon/AliExpress | 0.5-1.5 | No wire stripping; buy matching plug family for selected actuator
Battery | Protected LiPo with connector | 3.7 V 1200-2000 mAh protected LiPo JST-PH | 1 | 2 | Factory JST-PH plug | Adafruit/Pimoroni/CPC | 10-18 | Use protected cells only; never bypass protection PCB
Battery cartridge | USB-C LiPo charger module | Adafruit Micro-Lipo USB-C charger or SparkFun LiPo Charger Plus | 1 | 1 | JST-PH battery + USB-C charge | Adafruit/SparkFun/Pimoroni | 7-15 | The charger lives in the removable cartridge for tool-free swap/charge
Power switch | Inline JST-PH switch cable | JST-PH male-female switch harness | 1 | 1 | Pre-crimped inline switch | Adafruit/Amazon | 2-4 | Optional physical off switch before first flash
Mic array | Plug-in mic module | Adafruit I2S MEMS Microphone breakout or Seeed XIAO Sense onboard mic | 1-4 | 4-8 | STEMMA/Qwiic where possible or bundled no-solder adapter | Adafruit/Seeed/Pimoroni | 5-8 | Starter uses one onboard/plug-in mic; research build distributes mics around bay windows
Fasteners | Magnets | 3x1 mm N52 nickel-coated disc magnets | 24 | 40 | Press-fit with CA/epoxy; no electrical role | Amazon/Magnet Expert | 0.05-0.12 | Keep polarity consistent; not for children or pacemaker-adjacent handling
Fasteners | Snap-fit backup screws | M2 nylon thumb screws or M2.5 captive thumb screws | 4 | 6 | Hand-tightened only | Accu/Amazon | 0.20-0.60 | Optional backup for high-motion testing; no screwdriver required if thumb screws are used
Print material | FDM hard shell | PETG or PA12/PA12-CF filament | 1 spool | 1 spool | N/A | Prusa/Polymaker/Bambu/3DXTech | 25-60 | PETG is easiest; PA12-CF is tougher but requires dry filament
Print material | Flexible strap/liner | TPU 85A-95A filament | 1 spool | 1 spool | N/A | Prusa/Polymaker/NinjaTek | 25-45 | Use for skin-side comfort and cable channels
Print material | Resin option | ISO 10993 biocompatible surgical-guide resin | 500 g | 500 g | N/A | Formlabs/Phrozen/Loctite | 80-180 | If resin is not certified for skin | fully seal skin contact surfaces
Skin seal | Gasket/overmold | Medical-grade silicone sheet or Dragon Skin class silicone | 1 | 1 | N/A | Smooth-On/specialist suppliers | 18-35 | Do not leave uncured silicone on skin; follow supplier cure documentation
Labels | Beginner cable labels | Wrap-around numbered cable labels A00-A63 | 1 pack | 1 pack | N/A | Amazon/office suppliers | 4-8 | Critical for zero-electronics builders
Tools | Required non-electronics tools | 3D printer and USB-C cable | 1 | 1 | N/A | Existing tools | 0 | No soldering iron; no crimper; no wire stripper; no multimeter required for starter guide

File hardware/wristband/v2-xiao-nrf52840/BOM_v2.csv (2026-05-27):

Category | Part | Recommended 2026 example | Qty per build | Connector / no-solder detail | Supplier examples | Approx unit GBP May 2026 | Notes
MCU module | XIAO nRF52840 (Sense) | Seeed Studio XIAO nRF52840 Sense | 1 | USB-C preassembled; castellated 14-pin; onboard PDM mic + IMU on Sense variant | Seeed/Pimoroni/Mouser/DigiKey | 10-18 | Primary v2 board. nRF52840 = direct evolution of micro:bit v2 nRF52833. BLE 5.x + onboard LiPo charger. Non-Sense XIAO nRF52840 is fine when an external mic or phone-only audio is used.
Haptic driver | DRV2605L breakout (STEMMA QT) | Adafruit DRV2605L Haptic Motor Controller (PID 2305) or generic STEMMA QT clone | 1 | JST-SH STEMMA QT in/out + 2-pin screw terminal or JST to actuator | Adafruit/Pimoroni/DigiKey | 7-9 | Drives one LRA with onboard waveform ROM. Add a second module + I2C address change (open ADDR jumper) or a TCA9548A for >1 driver.
I2C mux (optional) | TCA9548A breakout | Adafruit TCA9548A STEMMA QT (PID 5626) | 0-1 | JST-SH STEMMA QT | Adafruit/Pimoroni/DigiKey | 7-9 | Needed only when running >2 DRV2605L modules with conflicting addresses.
Actuator | Pre-wired LRA coin motor (10 mm) | Precision Microdrives C10-100 LRA with JST-PH lead or Jinlong G1040003D | 2-4 | Factory-crimped 2-pin JST-PH lead | Precision Microdrives/Jinlong/Pimoroni | 2.5-4.5 | 2 LRAs = comfortable daily wear; 4 LRAs = richer spatial cue. Sandwich between XIAO and lid; thermal pad against case wall.
Battery | Thin protected LiPo 3.7 V 300-500 mAh | LP502535 (~400 mAh) or LP402535 (~300 mAh) with JST-PH | 1 | Factory JST-PH plug | Adafruit/Pimoroni/CPC/vetted AliExpress | 5-10 | Use protected cells only. 502535 fits the default 35x25x5.2 mm pocket. Charged via XIAO USB-C or magnetic pogo dock.
Charging dock | 2-pin magnetic pogo pair | Adafruit magnetic pogo connector pair (PID 5358) or 4-pin keyed magnetic pogo | 1 | Pre-wired pigtails to VBUS + GND | Adafruit/Amazon | 3-6 | Magnetic pogo on case underside; dock side wires to any USB-C 5 V source. Keyed polarity required.
Cable | JST-SH 4-pin STEMMA QT cable | 50 mm Qwiic/STEMMA QT cable | 1-2 | Pre-crimped plug-to-plug | Adafruit/SparkFun/Pimoroni | 1-2 | XIAO -> DRV2605L (use a Qwiic-to-castellated breakout or solder 4 wires once; v2 starter target keeps it no-solder via a XIAO expansion board).
XIAO expansion board (recommended for no-solder) | Seeed Studio Expansion Board Base for XIAO (Grove + battery JST) | 1 | Grove I2C + JST 2-pin battery; XIAO clicks in | Seeed/Pimoroni/Mouser | 5-9 | Provides Grove I2C to a Grove-to-STEMMA QT cable | plus JST-PH battery socket. Lets a beginner build the whole device with zero soldering.
Cable | Grove to STEMMA QT/Qwiic cable | SparkFun PRT-15109 or Adafruit 4528 | 1 | Pre-crimped 4-pin | SparkFun/Adafruit | 1.5-3 | Bridges XIAO expansion Grove to DRV2605L STEMMA QT.
Mic vent | IP67 acoustic membrane dot | PUI Audio/Gore acoustic vent 3-5 mm | 1 | Adhesive backed | DigiKey/Mouser | 0.40-0.80 | Only needed when XIAO Sense onboard PDM mic is used through the lid vent.
Fasteners | Snap-fit captive nuts (optional) | M1.6 brass heat-set inserts or nylon M1.6 screws | 4 | Press-fit / hand-tightened | Accu/Amazon | 0.10-0.50 | Default v2 uses snap-fit lid only; screws are optional for sport use.
Strap | 20-22 mm quick-release sport band | Any community parametric Apple-Watch-Ultra-style TPU/silicone band from Printables/MakerWorld | 1 | Standard 20 mm or 22 mm spring bars | Printables/MakerWorld/Amazon | 0-12 | Drop-in. Recommend printing a TPU 95A band from a CC-licensed community design.
Strap pins | Quick-release spring bars 20/22 mm | Stainless 1.5 mm spring bars | 2 | Hand-fit | Amazon/Watch parts | 1-3 | Match lug_width_mm parameter.
Print material | FDM hard shell | PETG or PA12-CF filament | ~80 g | N/A | Prusa/Polymaker/Bambu/3DXTech | 2-5 per build | 0.12 mm layer | 4 perimeters | 30% gyroid for case + lid.
Print material | Flexible strap/skin liner | TPU 95A filament | ~30 g | N/A | Prusa/Polymaker/NinjaTek | 1-3 per build | Used for integrated_tpu strap_style or printed bands.
Skin seal | Soft gasket | 1 mm self-adhesive EPDM/silicone foam strip | 1 | N/A | RS/Amazon | 1-3 | Optional: line the seal groove for IP-ish splash resistance.
Tools | Required tools | 3D printer + USB-C cable | 1 | N/A | Existing | 0 | No soldering iron required when using the XIAO Expansion Board path.

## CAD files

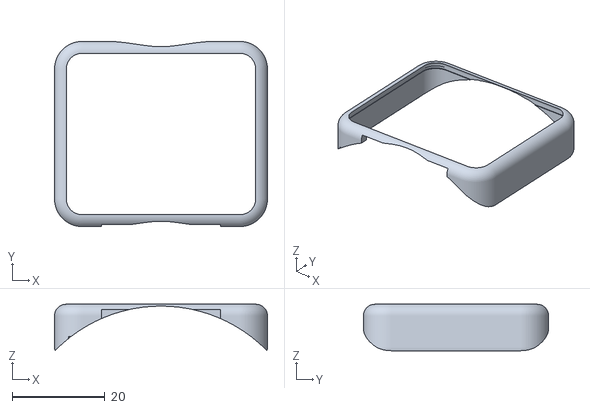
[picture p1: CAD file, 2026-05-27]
hardware/wristband/v2-xiao-nrf52840/print_pack/stl/openhear_v2_case.stl
46.0 x 40.0 x 10.0

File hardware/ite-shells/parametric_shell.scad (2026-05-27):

// ⚠️ EXPERIMENTAL — NOT A MEDICAL DEVICE
// This file is part of OpenHear, an open-source hearing aid project.
// It has not been evaluated by any regulatory body. Consult an audiologist
// before using any hearing device. Use at your own risk.
// License: MIT
//
// parametric_shell.scad — Parametric ITE (In-The-Ear) Hearing Aid Shell
// =====================================================================
// A fully parameterized OpenSCAD model for generating custom ITE hearing
// aid shells. All critical dimensions are exposed as variables so that
// the shell can be adapted to individual ear-canal impressions.
//
// Coordinate convention:
//   X = medial-lateral   (positive toward ear canal)
//   Y = anterior-posterior
//   Z = superior-inferior (positive upward)
//
// All dimensions in millimetres (mm).

// ── User Parameters ─────────────────────────────────────────────────

// --- Canal geometry ---
canal_depth       = 12.0;   // depth of the canal portion [mm]
canal_dia_tip     =  5.0;   // diameter at the canal tip (medial end) [mm]
canal_dia_base    =  7.5;   // diameter at the canal base (junction with shell body) [mm]
canal_taper_angle =  atan2((canal_dia_base - canal_dia_tip) / 2, canal_depth);

// --- Shell body ---
shell_length      = 18.0;   // overall length of the concha / body portion [mm]
shell_width       = 14.0;   // width of the body (anterior-posterior) [mm]
shell_height      = 11.0;   // height of the body (superior-inferior) [mm]
wall_thickness    =  1.2;   // shell wall thickness [mm]

// --- Faceplate ---
faceplate_length  = 14.0;   // faceplate X extent [mm]
faceplate_width   = 12.0;   // faceplate Y extent [mm]
faceplate_thick   =  1.5;   // faceplate thickness [mm]
snap_lip_height   =  0.8;   // snap-fit retention lip height [mm]
snap_lip_depth    =  0.4;   // snap-fit lip radial protrusion [mm]

// --- Vent (anti-occlusion) ---
vent_diameter     =  1.4;   // vent bore diameter [mm] (typ. 0.8–2.0)
vent_offset_y     =  2.5;   // lateral offset from canal centre [mm]

// --- Microphone ports (dual, for basic beamforming) ---
mic_port_dia      =  1.0;   // microphone port opening diameter [mm]
mic1_pos          = [ 3.0,  3.5, shell_height / 2];  // front mic [mm]
mic2_pos          = [-3.0,  3.5, shell_height / 2];  // rear mic [mm]
mic_port_depth    =  faceplate_thick + 0.5;           // bore depth through faceplate [mm]

// --- Receiver (speaker) bore ---
receiver_bore_dia =  1.8;   // receiver sound-outlet bore diameter [mm]
receiver_bore_len =  canal_depth + 2.0;  // bore runs full canal length [mm]

// --- Battery compartment (size 10 zinc-air cell: ⌀5.8 × 3.6 mm) ---
batt_dia          =  6.2;   // compartment inner diameter (clearance fit) [mm]
batt_height       =  4.0;   // compartment depth [mm]
batt_pos          = [0, -2.0, 0];  // centre position inside shell body [mm]

// --- Wax guard recess ---
wax_recess_dia    =  2.5;   // wax guard seat outer diameter [mm]
wax_recess_depth  =  1.0;   // recess depth at canal tip [mm]

// --- Internal wire channel ---
wire_channel_dia  =  1.2;   // routing channel for receiver / mic wires [mm]

// --- Lotus-effect microstructure (experimental) ---
pillar_dia        =  0.15;  // re-entrant pillar shaft diameter [mm]
pillar_cap_dia    =  0.25;  // mushroom cap diameter [mm]
pillar_height     =  0.30;  // total pillar height [mm]
pillar_spacing    =  0.40;  // centre-to-centre pitch [mm]

// --- Rendering quality ---
$fn = 64;  // global facet count for curved surfaces


// ── Modules ─────────────────────────────────────────────────────────

// ---- shell_body() ----
// Main hollow concha-filling body, modelled as a rounded box with
// uniform wall thickness removed from the interior.
module shell_body() {
    difference() {
        // Outer hull — rounded rectangular solid
        hull() {
            for (sx = [-1, 1], sy = [-1, 1])
                translate([
                    sx * (shell_length / 2 - 3),
                    sy * (shell_width / 2 - 3),
                    0
                ])
                cylinder(r = 3, h = shell_height);
        }

        // Inner cavity (offset inward by wall_thickness)
        translate([0, 0, wall_thickness])
        hull() {
            for (sx = [-1, 1], sy = [-1, 1])
                translate([
                    sx * (shell_length / 2 - 3 - wall_thickness),
                    sy * (shell_width / 2 - 3 - wall_thickness),
                    0
                ])
                cylinder(r = 3, h = shell_height + 1);  // extend past outer hull to open top
        }
    }
}


// ---- canal_portion() ----
// Tapered canal tip extending from the medial face of the shell body.
// The taper matches the ear-canal geometry from impression data.
module canal_portion() {
    translate([0, 0, -canal_depth])
    difference() {
        // Outer tapered cylinder
        cylinder(
            d1 = canal_dia_tip,
            d2 = canal_dia_base,
            h  = canal_depth
        );

        // Hollow core
        translate([0, 0, -0.1])
        cylinder(
            d1 = canal_dia_tip - 2 * wall_thickness,
            d2 = canal_dia_base - 2 * wall_thickness,
            h  = canal_depth + 0.2
        );
    }
}


// ---- faceplate() ----
// Removable lateral faceplate with a perimeter snap-fit retention lip.
// Houses microphone ports and battery door.
module faceplate() {
    translate([0, 0, shell_height]) {
        // Main plate
        hull() {
            for (sx = [-1, 1], sy = [-1, 1])
                translate([
                    sx * (faceplate_length / 2 - 2),
                    sy * (faceplate_width / 2 - 2),
                    0
                ])
                cylinder(r = 2, h = faceplate_thick);
        }

        // Snap-fit lip (perimeter skirt that clicks into shell body)
        difference() {
            hull() {
                for (sx = [-1, 1], sy = [-1, 1])
                    translate([
                        sx * (faceplate_length / 2 - 2),
                        sy * (faceplate_width / 2 - 2),
                        -snap_lip_height
                    ])
                    cylinder(r = 2 + snap_lip_depth, h = snap_lip_height);
            }
            // Remove interior so only lip ring remains
            hull() {
                for (sx = [-1, 1], sy = [-1, 1])
                    translate([
                        sx * (faceplate_length / 2 - 2),
                        sy * (faceplate_width / 2 - 2),
                        -snap_lip_height - 0.1
                    ])
                    cylinder(r = 2, h = snap_lip_height + 0.2);
            }
        }
    }
}


// ---- vent_channel() ----
// Through-bore vent running parallel to the canal axis for pressure
// equalisation and anti-occlusion. Reduces the occlusion effect by
// allowing low-frequency energy to escape.
module vent_channel() {
    total_length = canal_depth + shell_height + faceplate_thick + 2;
    translate([0, vent_offset_y, -canal_depth - 1])
        cylinder(d = vent_diameter, h = total_length);
}


// ---- mic_port(position) ----
// Cylindrical bore through the faceplate for a MEMS microphone.
// Two ports placed apart enable a simple endfire beamformer.
module mic_port(position) {
    translate(position)
        cylinder(d = mic_port_dia, h = mic_port_depth, center = false);
}


// ---- receiver_bore() ----
// Sound outlet channel running from the receiver cavity through the
// canal tip. Terminates at the wax-guard recess.
module receiver_bore() {
    translate([0, 0, -canal_depth - 1])
        cylinder(d = receiver_bore_dia, h = receiver_bore_len);
}


// ---- battery_compartment() ----
// Cylindrical pocket sized for a standard zinc-air button cell.
// Positioned inside the shell body; accessed via faceplate removal.
module battery_compartment() {
    translate([batt_pos[0], batt_pos[1], wall_thickness + 0.5])
        cylinder(d = batt_dia, h = batt_height);
}


// ---- wax_guard_recess() ----
// Shallow circular recess at the canal tip for a push-fit cerumen
// (wax) guard / filter. Protects the receiver from debris ingress.
module wax_guard_recess() {
    translate([0, 0, -canal_depth - wax_recess_depth + 0.01])
        cylinder(d = wax_recess_dia, h = wax_recess_depth);
}


// ---- wire_channel() ----
// Internal routing channel for receiver and microphone wiring.
// Runs from the battery compartment area down through the canal.
module wire_channel() {
    wire_total = canal_depth + shell_height / 2 + 1;
    translate([wire_channel_dia, -wire_channel_dia, -canal_depth])
        cylinder(d = wire_channel_dia, h = wire_total);
}
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

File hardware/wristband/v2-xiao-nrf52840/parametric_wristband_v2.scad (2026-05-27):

/* OpenHear aids-free wristband v2 "Premium Slim" parametric CAD
   Fork of hardware/wristband/cad/parametric_wristband_v1.scad.
   Target: daily-wear, Apple Watch Ultra / Whoop 4.0 style rectangular case
           on the Seeed Studio XIAO nRF52840 (or XIAO nRF52840 Sense).
   Hardware licence: CERN-OHL-S-2.0
   Docs licence:     CC-BY-SA-4.0

   Design intent (do not regress from v1):
   - Same 3-byte BLE haptic packet contract  [sound_class_id, intensity, pattern_id]
   - Same 7 YAMNet sound classes + audiogram JSON intensity weighting
   - Same Burgess-Principle local-only data path; BLE is companion-only
   - 100% open-source, sovereign, local-first, individually buildable

   Form factor goals:
   - Rectangular slim case, 42-46 mm long x 36-40 mm wide
   - <= 12 mm total stack thickness (wrist side + electronics + lid)
   - Curved wrist underside (cylindrical sweep) for comfortable contact
   - Internal pockets for: 1x XIAO nRF52840(Sense), 2-4x LRA (coin or 10 mm),
     1x thin 300-500 mAh LiPo, optional 1-2x DRV2605L STEMMA QT carriers,
     pogo/magnetic charging contacts on the lid edge
   - Subtle engraved "OpenHear" logo on the lid
   - IP-ish lid seal lips (mating tongue + groove)
   - 20-22 mm quick-release lug pockets OR integrated TPU strap option
   - FDM/TPU printable, 0.8-1.2 mm walls, 2-3 mm fillets, minimal supports
*/

$fn = 96;

// ============================================================================
// PARAMETERS
// ============================================================================

// ---- Build selection -------------------------------------------------------
build_part      = "case";       // [case, lid, strap_tpu, jig, all_exploded]
strap_style     = "lugs";       // [lugs, integrated_tpu, none]
show_cutaway    = false;        // half-section preview
preview_pcb     = false;        // draw XIAO + LRAs as solids for visual check

// ---- Outer case dimensions (Apple Watch Ultra / Whoop 4.0 feel) -----------
case_length_mm        = 46.0;   // [40:1:52]   long axis (lug-to-lug body) — increased from 44 to compensate for wall fix
case_width_mm         = 40.0;   // [34:1:44]   short axis (across wrist) — increased from 38 to compensate for wall fix
case_total_height_mm  = 11.8;   // [9:0.2:13]  total stack thickness <= 12 mm
case_corner_r_mm      = 6.0;    // [4:0.5:9]   rounded rectangle corner radius
wrist_radius_mm       = 32.0;   // [22:1:45]   cylindrical sweep of underside
wall_thickness_mm     = 2.0;    // [0.8:0.1:2.4] — increased from 1.0: 5× 0.4 mm / 4× 0.5 mm nozzle perimeters
floor_thickness_mm    = 1.2;    // [0.8:0.1:1.6] — increased from 1.1 for print consistency
lid_thickness_mm      = 1.2;    // [0.8:0.1:1.8]
fillet_r_mm           = 2.5;    // [1.5:0.1:3.0]
print_tolerance_mm    = 0.20;   // [0.10:0.05:0.40]
skin_relief_mm        = 0.30;   // gentle relief band on wrist face

// ---- XIAO nRF52840 (Sense) pocket -----------------------------------------
// Datasheet: 21.0 x 17.5 mm; height ~3.5 mm incl. shield; USB-C on short side.
xiao_len_mm           = 21.0;
xiao_wid_mm           = 17.5;
xiao_thk_mm           = 3.6;
xiao_usbc_w_mm        = 9.4;
xiao_usbc_h_mm        = 3.6;
xiao_offset_y_mm      = 6.0;    // shift toward "top" of case (away from lugs)

// ---- Battery pocket (thin LiPo, 300-500 mAh) ------------------------------
// Examples: 502535 (5x25x35 mm, ~400 mAh) or 402030 (~250 mAh) or 552535.
battery_len_mm        = 35.0;   // [25:1:42]
battery_wid_mm        = 25.0;   // [18:1:34]
battery_thk_mm        = 5.2;    // [3.5:0.1:6.5]
battery_clearance_mm  = 0.4;

// ---- Haptic actuators ------------------------------------------------------
// Default: 2 small LRA coins (10 mm) flanking the centre line.
// Bump to 4 for richer spatialisation (still fits 44 x 38 mm shell).
actuator_count        = 2;      // [2,3,4]
actuator_d_mm         = 10.0;   // 10 mm LRA coin
actuator_h_mm         = 3.4;
actuator_pitch_mm     = 18.0;   // centre-to-centre across long axis

// ---- DRV2605L STEMMA QT carrier (optional second slot) --------------------
// Adafruit DRV2605L STEMMA QT outline ~ 17.8 x 17.8 mm, ~3 mm thick.
drv_carrier_pocket    = true;
drv_len_mm            = 17.8;
drv_wid_mm            = 17.8;
drv_thk_mm            = 3.2;

// ---- Pogo / magnetic charging pads ----------------------------------------
// Two-pin pogo on the bottom edge of the case (VBUS + GND).
pogo_pin_d_mm         = 2.6;
pogo_pin_pitch_mm     = 4.0;
pogo_pad_recess_mm    = 0.6;

// ---- Lid + IP-ish seal -----------------------------------------------------
seal_lip_w_mm         = 1.2;
seal_lip_h_mm         = 0.7;
seal_lip_relief_mm    = 0.15;   // groove side relief for compression
lid_screw_count       = 0;      // 0 = snap-fit only; 4 = M1.6 corner screws
lid_screw_d_mm        = 1.7;
lid_screw_head_d_mm   = 3.0;

// ---- Strap interface -------------------------------------------------------
lug_width_mm          = 22.0;   // [20:1:24] standard quick-release width
lug_thickness_mm      = 3.0;
lug_pin_d_mm          = 1.6;    // M1.5 spring-bar pin clearance
lug_recess_depth_mm   = 1.8;
tpu_strap_thk_mm      = 2.0;    // integrated_tpu band initial section
tpu_strap_total_mm    = 160;    // unwrapped length per side
tpu_strap_taper_pct   = 0.85;

// ---- Branding --------------------------------------------------------------
engrave_logo          = true;
logo_text             = "OpenHear";
logo_font             = "Liberation Sans:style=Bold";
logo_size_mm          = 3.2;
logo_depth_mm         = 0.4;

// ---- Mic vent (optional, only when XIAO Sense PDM mic is enabled) ---------
mic_vent_d_mm         = 0.9;
mic_vent_offset_mm    = 6.0;    // from case centre toward "top" edge

// ============================================================================
// DERIVED
// ============================================================================
inner_len    = case_length_mm - 2 * wall_thickness_mm;
inner_wid    = case_width_mm  - 2 * wall_thickness_mm;
inner_h      = case_total_height_mm - floor_thickness_mm - lid_thickness_mm;
inner_corner = max(case_corner_r_mm - wall_thickness_mm, 0.6);
lid_corner   = case_corner_r_mm;

// ============================================================================
// PRIMITIVES
// ============================================================================
module rounded_rect(size, r) {
    // 2D rounded rectangle via minkowski-free hull of corner circles
    w = size[0]; d = size[1];
    hull() {
        for (x = [-w/2 + r, w/2 - r])
            for (y = [-d/2 + r, d/2 - r])
                translate([x, y]) circle(r = r);
    }
}

module rounded_slab(size, r, fillet = 1.2) {
    // 3D rounded-corner slab with top/bottom fillets via minkowski.
    w = size[0]; d = size[1]; h = size[2];
    f = min(fillet, h/2 - 0.05, r - 0.05);
    minkowski() {
        linear_extrude(height = max(h - 2*f, 0.01), center = true)
            rounded_rect([w - 2*f, d - 2*f], max(r - f, 0.4));
        sphere(r = f);
    }
}

module wrist_curve_cut() {
    // Cylindrical removal that gives the underside a comfortable wrist sweep.
    translate([0, 0, -wrist_radius_mm + (case_total_height_mm/2) - 0.4])
        rotate([90, 0, 0])
            cylinder(r = wrist_radius_mm, h = case_length_mm * 2.2, center = true);
}

// ============================================================================
// POCKETS
// ============================================================================
module xiao_pocket() {
    translate([0, xiao_offset_y_mm, -inner_h/2 + xiao_thk_mm/2 + 0.2])
        cube([xiao_len_mm + 2*print_tolerance_mm,
              xiao_wid_mm + 2*print_tolerance_mm,
              xiao_thk_mm + 2*print_tolerance_mm],
             center = true);
    // USB-C cut-out toward the "top" edge of the case
    translate([0,
               xiao_offset_y_mm + xiao_wid_mm/2 + wall_thickness_mm,
               -inner_h/2 + xiao_usbc_h_mm/2 + 0.6])
        cube([xiao_usbc_w_mm + 2*print_tolerance_mm,
              wall_thickness_mm * 4,
              xiao_usbc_h_mm + 2*print_tolerance_mm],
             center = true);
}

module drv_pocket() {
    if (drv_carrier_pocket)
        translate([-(inner_len/2 - drv_len_mm/2 - 1.2),
                   xiao_offset_y_mm - xiao_wid_mm/2 - drv_wid_mm/2 - 1.2,
                   -inner_h/2 + drv_thk_mm/2 + 0.2])
            cube([drv_len_mm + 2*print_tolerance_mm,
                  drv_wid_mm + 2*print_tolerance_mm,
                  drv_thk_mm + 2*print_tolerance_mm],
                 center = true);
}
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

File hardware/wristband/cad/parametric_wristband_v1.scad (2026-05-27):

/* OpenHear aids-free wristband v1 parametric CAD
   Hardware licence: CERN-OHL-S-2.0
   Nothing in/on the ear; wrist is the complete system; skin is the transducer.
*/
$fn = 96;

wrist_circumference_mm = 170; // [140:1:220]
actuator_count = 24;          // [24,64,128]
ring_count_override = 0;      // 0 = infer 24->1, 64->4, 128->8
strap_width_mm = 34;
body_height_mm = 8.2;
wall_thickness_mm = 1.8;
resin_tolerance_mm = 0.35;    // validated target 0.30-0.50 mm
skin_gap_mm = 0.45;
silicone_overmold_mm = 1.0;
actuator_pocket_d_mm = 10.5;
actuator_pocket_h_mm = 3.8;
mic_count = 8;                // [8,16]
mic_port_d_mm = 1.15;
flex_channel_w_mm = 7.0;
flex_channel_h_mm = 1.0;
seal_lip_w_mm = 1.4;
seal_lip_h_mm = 0.8;
battery_len_mm = 45;
battery_w_mm = 25;
battery_h_mm = 8;
battery_clearance_mm = 0.5;
lug_len_mm = 15;
lug_hole_d_mm = 2.2;
show_cutaway = false;

inner_radius_mm = wrist_circumference_mm / (2 * PI);
outer_radius_mm = inner_radius_mm + body_height_mm;
ring_count = ring_count_override > 0 ? ring_count_override :
    (actuator_count <= 24 ? 1 : (actuator_count <= 64 ? 4 : 8));
columns = ceil(actuator_count / ring_count);
arc_gap_deg = 34;
active_arc_deg = 360 - arc_gap_deg;
ring_pitch_mm = strap_width_mm / ring_count;

module rounded_box(size, radius) {
    hull() for (x = [-size[0]/2 + radius, size[0]/2 - radius])
        for (y = [-size[1]/2 + radius, size[1]/2 - radius])
            for (z = [-size[2]/2 + radius, size[2]/2 - radius])
                translate([x, y, z]) sphere(r = radius);
}

module annular_segment(r_inner, r_outer, height, start_deg, end_deg) {
    step = 2;
    outer = [for (a = [start_deg:step:end_deg]) [r_outer * cos(a), r_outer * sin(a)]];
    inner = [for (a = [end_deg:-step:start_deg]) [r_inner * cos(a), r_inner * sin(a)]];
    linear_extrude(height = height, center = true) polygon(concat(outer, inner));
}

module actuator_pocket(angle_deg, z_pos) {
    rotate([0, 0, angle_deg])
        translate([inner_radius_mm + wall_thickness_mm + actuator_pocket_h_mm / 2, 0, z_pos])
            rotate([0, 90, 0])
                cylinder(d = actuator_pocket_d_mm + resin_tolerance_mm,
                         h = actuator_pocket_h_mm + resin_tolerance_mm,
                         center = true);
}

module flex_channel(angle_deg, z_pos) {
    rotate([0, 0, angle_deg])
        translate([inner_radius_mm + wall_thickness_mm + 1.8, 0, z_pos])
            cube([flex_channel_h_mm, flex_channel_w_mm, ring_pitch_mm * 0.72], center = true);
}

module mic_port(angle_deg) {
    rotate([0, 0, angle_deg])
        translate([outer_radius_mm - wall_thickness_mm / 2, 0, strap_width_mm / 2 - 2.2])
            rotate([0, 90, 0]) cylinder(d = mic_port_d_mm, h = wall_thickness_mm * 3, center = true);
}

module ip67_seal_lips() {
    annular_segment(inner_radius_mm + 0.25, inner_radius_mm + seal_lip_w_mm, seal_lip_h_mm,
                    -active_arc_deg / 2, active_arc_deg / 2);
    translate([0, 0, strap_width_mm / 2 - seal_lip_h_mm / 2])
        annular_segment(inner_radius_mm + 0.25, inner_radius_mm + seal_lip_w_mm, seal_lip_h_mm,
                        -active_arc_deg / 2, active_arc_deg / 2);
    translate([0, 0, -strap_width_mm / 2 + seal_lip_h_mm / 2])
        annular_segment(inner_radius_mm + 0.25, inner_radius_mm + seal_lip_w_mm, seal_lip_h_mm,
                        -active_arc_deg / 2, active_arc_deg / 2);
}

module strap_lugs() {
    for (side = [-1, 1]) rotate([0, 0, side * (active_arc_deg / 2 + 4)])
        translate([inner_radius_mm + body_height_mm / 2, 0, 0])
            difference() {
                rounded_box([lug_len_mm, 7, strap_width_mm * 0.86], 2);
                rotate([90, 0, 0]) cylinder(d = lug_hole_d_mm, h = 10, center = true);
            }
}

module battery_cartridge() {
    translate([0, -outer_radius_mm - lug_len_mm / 2, 0]) difference() {
        rounded_box([battery_w_mm + 2*battery_clearance_mm + 3,
                     battery_len_mm + 2*battery_clearance_mm + 3,
                     battery_h_mm + 3], 3);
        rounded_box([battery_w_mm + 2*battery_clearance_mm,
                     battery_len_mm + 2*battery_clearance_mm,
                     battery_h_mm + battery_clearance_mm], 2);
        translate([0, battery_len_mm / 2 + 1, 0]) cube([battery_w_mm * 0.5, 4, battery_h_mm + 5], center = true);
    }
}

module wristband_body() {
    difference() {
        union() {
            annular_segment(inner_radius_mm, outer_radius_mm, strap_width_mm, -active_arc_deg / 2, active_arc_deg / 2);
            ip67_seal_lips(); strap_lugs(); battery_cartridge();
        }
        annular_segment(inner_radius_mm - 0.1, inner_radius_mm + silicone_overmold_mm + skin_gap_mm,
                        strap_width_mm + 2, -active_arc_deg / 2, active_arc_deg / 2);
        for (i = [0:actuator_count - 1]) {
            ring = floor(i / columns); col = i % columns;
            angle = -active_arc_deg / 2 + (col + 0.5) * active_arc_deg / columns;
            z = -strap_width_mm / 2 + ring_pitch_mm * (ring + 0.5);
            actuator_pocket(angle, z); flex_channel(angle, z);
        }
        for (m = [0:mic_count - 1]) mic_port(-active_arc_deg / 2 + (m + 0.5) * active_arc_deg / mic_count);
        for (a = [-active_arc_deg / 2 + 8, active_arc_deg / 2 - 8])
            rotate([0, 0, a]) translate([outer_radius_mm - 1, 0, 0]) rotate([0, 90, 0])
                cylinder(d = 0.85, h = 5, center = true);
        if (show_cutaway) translate([-outer_radius_mm, -outer_radius_mm, -strap_width_mm])
            cube([outer_radius_mm * 2, outer_radius_mm * 2, strap_width_mm * 2]);
    }
}

wristband_body();

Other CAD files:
hardware/wristband/v1.5-no-solder/cad/parametric_modular_wristband_v1.5.scad

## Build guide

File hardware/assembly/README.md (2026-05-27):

# assembly/ — Build Guide

A step-by-step guide to building your OpenHear hearing aid. Written for someone who has never soldered before. If you have soldered before, you will move faster, but read every step anyway — the safety-critical steps are marked and must not be skipped.

---

## 1. Tools Needed

You do not need expensive tools. A basic kit costs about £40 and will last for years.

| Tool | What It's For | Approx Cost | Notes |
|---|---|---|---|
| Soldering iron (temperature-controlled) | Joining wires to connectors and circuit boards | £15–25 | Entry-level is fine. Look for adjustable temperature (set to 350°C for lead-free solder). Recommended: Pinecil or TS100 |
| Lead-free solder, 0.8mm diameter | Filler material for solder joints | £5 | 0.8mm is thin enough for small joints. Lead-free (Sn99.3/Cu0.7) is safer to work with. Do not use leaded solder |
| Wire strippers | Removing insulation from wire ends | £5 | Adjustable type recommended. Set for 30 AWG wire |
| Flush cutters | Trimming wire and component leads | £5 | Small, sharp. One clean cut — don't use scissors |
| Helping hands / third hand tool | Holding components while you solder | £8 | Alligator clips on an adjustable arm. Essential when you only have two hands |
| Multimeter | Measuring voltage, resistance, and continuity | £10–15 | Basic digital multimeter. Must have continuity beep function |
| Magnifying glass or loupe | Inspecting solder joints | £3 | 5x–10x magnification. A head-mounted magnifier works too |

**Optional but helpful:**
- Solder wick or solder sucker (for fixing mistakes)
- Silicone soldering mat (protects your work surface)
- Fume extractor or desk fan (for solder fume ventilation)

---

## 2. Workspace Setup

### Ventilation

Solder fume (flux smoke) is an irritant. Do not breathe it directly.

- Work near an open window, or
- Use a small desk fan blowing fumes away from your face, or
- Use a fume extractor with activated carbon filter

You do not need laboratory-grade ventilation. A gentle breeze away from your face is sufficient.

### ESD Safety

ESD (Electrostatic Discharge) can damage the Tympan board. Basic precautions:

- Touch a grounded metal object before handling the Tympan (a radiator, the metal case of a plugged-in computer)
- Work on an anti-static mat if you have one. If not, avoid working on carpet or synthetic surfaces
- Handle the Tympan by its edges. Avoid touching the components on the board

### Lighting

Good lighting prevents mistakes. Use a desk lamp positioned to eliminate shadows on your work area. Daylight-colour LED is ideal.

---

## 3. Tier 1 Build: Explorer (~30 minutes)

**What you're building:** Tympan connected to headphones and a lavalier microphone. Your audiogram loaded as a DSP configuration. Real-time personalised audio processing.

**Components needed:** Tympan Rev F, wired over-ear headphones, 3.5mm lavalier mic, USB cable. See [BOM](../BOM.md) Tier 1.

### Steps

**3.1 — Unbox and inspect the Tympan**

Open the Tympan packaging. Verify you have the board, USB cable, and any included documentation. Inspect the board for obvious damage (bent pins, cracked components). If anything looks damaged, contact Tympan support before proceeding.

**3.2 — Install Arduino IDE and Tympan Library**

1. Download and install [Arduino IDE](https://www.arduino.cc/en/software) (version 2.x recommended)
2. In Arduino IDE, go to Tools → Board → Boards Manager. Search for "Teensy" and install Teensyduino
3. Go to Sketch → Include Library → Manage Libraries. Search for "Tympan" and install the Tympan Library
4. Verify installation: File → Examples → Tympan Library. You should see example sketches

**3.3 — Connect headphones and microphone**

1. Plug the headphones into the Tympan's 3.5mm output jack
2. Plug the lavalier microphone into the Tympan's 3.5mm input jack
3. Connect the Tympan to your computer via USB

**3.4 — Generate your personalised sketch**

Run the OpenHear bridge script to generate an Arduino sketch from your audiogram:

```bash
# Generate a sketch for your right ear:
python -m hardware.tympan.audiogram_to_tympan audiogram/data/burgess_2021.json my_sketch.ino

# Or for both ears (binaural):
python -m hardware.tympan.audiogram_to_tympan audiogram/data/burgess_2021.json my_sketch.ino --binaural
```

Replace `burgess_2021.json` with your own audiogram file. The script prints a summary of the gain profile and DSP parameters it generated.

**3.5 — Upload the sketch**

1. Open the generated `.ino` file in Arduino IDE
2. Select board: Tools → Board → Teensy 4.1
3. Select port: Tools → Port → (your Tympan's USB port)
4. Click Upload (arrow button)
5. Wait for "Done uploading" message

**3.6 — Verify audio passthrough**

1. Put on the headphones
2. Speak into the lavalier microphone
3. You should hear your voice through the headphones with the gain profile applied
4. Sound should be clear, with no distortion at normal speaking levels
5. If you hear nothing: check connections, verify the sketch uploaded successfully
6. If you hear distortion: reduce the master gain in the sketch and re-upload

**3.7 — Fine-tune with Tympan Remote App**

1. Install the Tympan Remote App on your phone ([Android](https://play.google.com/store/apps/details?id=com.creare.tympanRemote) / [iOS](https://apps.apple.com/app/tympan-remote/id1530523124))
2. Enable Bluetooth on the Tympan (it should be enabled by default in the generated sketch)
3. Connect to the Tympan from the app
4. Adjust gain, compression, and noise reduction in real time
5. Find settings that sound best to you

**Tier 1 is complete.** You have a working, audiogram-personalised hearing device.

---

## 4. Tier 2 Build: Builder (3–4 hours)

**What you're building:** A wearable binaural hearing aid with BTE earpieces, custom ear moulds, balanced armature receivers, and a hardware MPO limiter circuit.

**Components needed:** Everything from Tier 1, plus Tympan Earpiece Kit, Knowles receivers, 3D printed ear moulds, impression kit, LiPo battery, wire and connectors. See [BOM](../BOM.md) Tier 2.

**Prerequisites:**
- Complete [Tier 1](#3-tier-1-build-explorer-30-minutes) first
- Read the [safety module](../safety/README.md) completely
- Make your ear moulds using the [shell/ guide](../shell/README.md)

### Steps

**4.1 — Connect the Tympan Earpiece Kit**

The Tympan Earpiece Kit includes left and right BTE housings with built-in dual MEMS microphones. Connect them to the Tympan board following the kit instructions.

1. Connect the earpiece cables to the Tympan's earpiece connectors
2. Verify microphone input: speak near the earpieces and check for signal in the Arduino Serial Monitor

**4.2 — Solder receiver wires**

Each Knowles balanced armature receiver has two solder pads. You need to attach thin wire (30 AWG silicone) to connect them to the Tympan's output.

1. Cut two 15cm lengths of 30 AWG silicone wire per receiver (4 total for binaural)
2. Strip 3mm of insulation from each end
3. Tin the wire tips: apply a small amount of solder to each stripped end
4. Tin the receiver pads: apply a tiny amount of solder to each pad on the receiver
5. Solder the wires to the receiver pads. This is the smallest soldering in the build — use magnification and steady hands. Touch the tinned wire to the tinned pad, briefly touch with the iron. The joint should be shiny and smooth
6. Allow to cool. Tug gently to verify the joint is solid
7. Slide heat shrink over each joint and shrink with the iron's heat or a heat gun

> **Tip:** If you've never soldered before, practice on some scrap wire first. Make 10 joints, inspect each one. A good joint is shiny, smooth, and conical. A bad joint is dull, blobby, or has visible gaps.

**4.3 — Install receivers in ear moulds**

1. Thread the receiver wire through the wire channel in the ear mould
2. Insert the receiver into the receiver bore. It should slide in with light pressure and hold by friction
3. Verify the receiver tip is flush with the medial (inner) end of the mould
4. Verify the wire exits cleanly from the lateral (outer) end without kinking

**4.4 — Build the MPO limiter circuit** ⚠️ SAFETY CRITICAL

**Read the [safety module](../safety/README.md#2-hardware-mpo-limiter-circuit) before starting this step.**

Use the [MPO calculator](../safety/mpo_calculator.py) to determine the correct component values for your audiogram:

```bash
python -m hardware.safety.mpo_calculator audiogram/data/burgess_2021.json
```

Build the circuit on a small piece of perfboard (stripboard):

1. Place the 100Ω series resistor on the perfboard
2. Place two zener diodes back-to-back (anode-to-anode) in parallel across the output
3. Solder all connections
4. Use the multimeter to verify:
   - Continuity from input to output through the resistor (should read ~100Ω)
   - No short circuit between output and ground (should read high resistance in both directions until zener voltage is reached)
5. Build one limiter circuit per ear (two total for binaural)

**4.5 — Connect limiter inline**

The limiter circuit goes between the Tympan's output and the receiver:

```
Tympan output → Limiter input → Limiter output → Receiver
```

1. Connect the Tympan output wire to the limiter input
2. Connect the limiter output to the receiver wire
3. Connect the limiter ground to the Tympan ground
4. Verify all connections with the multimeter (continuity check)

**4.6 — Upload binaural sketch**

Generate and upload a binaural sketch:

```bash
python -m hardware.tympan.audiogram_to_tympan audiogram/data/burgess_2021.json binaural.ino --binaural
```

Upload via Arduino IDE as in Tier 1.

**4.7 — Calibrate** ⚠️ SAFETY CRITICAL

Follow the [calibration procedure](../safety/README.md#4-calibration-procedure) completely. Do not skip this step. Do not wear the device until calibration is complete and all frequencies pass.

---

## 5. Tier 3 Build: Sovereign (2–3 days including print time)

**What you're building:** A fully custom integrated device with a precision-printed shell, integrated components, and calibrated with a measurement microphone.

**Components needed:** Everything from Tier 2, plus resin printer, biocompatible resin, calibration microphone. See [BOM](../BOM.md) Tier 3.

**Prerequisites:**
- Complete [Tier 2](#4-tier-2-build-builder-3-4-hours) first — you need a working system before integrating into a custom shell
- Read the [3D printing guide](../shell/README.md) completely

### Steps

**5.1 — Print custom shells**

Follow the complete [3D printing guide](../shell/README.md):

1. Take ear impressions with medical silicone
2. Scan impressions to STL
3. Add channels using the [parametric mould template](../shell/parametric_mould.md)
4. Print at 0.05mm layer height with biocompatible resin
5. Post-process: IPA wash, UV cure, sand

Allow 24 hours for printing and curing.

**5.2 — Integrate components into custom shell**

1. Install receivers into the custom moulds (same process as Tier 2, step 4.3)
2. Route wires through the shell channels
3. Mount the MPO limiter circuit inside the BTE housing (secure with hot glue or mounting tape)
4. Connect all wiring
5. Verify with multimeter: continuity through the signal chain, no shorts to ground

**5.3 — Full wiring**

1. Connect earpiece microphones to Tympan input
2. Connect MPO limiter output to receivers
3. Connect LiPo battery to Tympan
4. Verify the Tympan powers on from battery
5. Verify all audio paths with multimeter continuity check

**5.4 — Calibrate with measurement microphone** ⚠️ SAFETY CRITICAL

Use the Dayton Audio iMM-6 calibration microphone and a 2cc coupler:

1. Follow the [calibration procedure](../safety/README.md#4-calibration-procedure)
2. Measure output SPL at all audiometric frequencies
3. Verify MPO at all frequencies
4. Log all results to SD card
5. Do not proceed until all frequencies pass calibration

**5.5 — Wear testing**

1. Insert moulds (unpowered first — verify comfort)
2. Power on at minimum gain
3. Gradually increase to target gain
4. Wear for 1 hour — check comfort and sound quality
5. Wear for 4 hours — check for developing discomfort
6. Wear for 8 hours — full day test
7. Log any issues and iterate on fit or settings

---

## 6. Verification Checklist

Before using your OpenHear device for regular wear, every item on this list must be checked. No exceptions.

- [ ] **MPO limiter installed and tested** — hardware limiter circuit is in-line for both ears. Verified with multimeter (resistance reading across limiter matches expected value)
- [ ] **Calibration completed at all frequencies** — SPL output measured and verified at 250, 500, 1000, 2000, 3000, 4000, 6000, and 8000 Hz. All within ±3 dB of target
- [ ] **MPO verified** — output does not exceed target MPO at any frequency. Hardware limiter engages correctly
- [ ] **Feedback cancellation active** — no sustained whistling with moulds in place and gain at target levels
- [ ] **Battery life tested** — minimum 8 hours of continuous operation on a full charge
- [ ] **Comfort tested over 4+ hours** — no pain, no pressure points, no developing soreness
- [ ] **Emergency mute configured** — button or gesture to immediately mute output is configured and tested
- [ ] **Calibration log saved** — all calibration data saved to SD card with date and configuration details

---

## 7. Troubleshooting

### Feedback (Whistling)

**Symptom:** High-pitched whistling or squealing, especially at higher gain settings.

**Causes and fixes:**

| Cause | Fix |
|---|-----|
| Poor ear mould seal | Reprint mould with tighter fit (reduce canal diameter by 0.1mm). Check for wax buildup in ear canal |
| Gain too high at specific frequencies | Reduce gain at the feedback frequency. Check gain ceiling settings |
| Feedback cancellation not active | Verify feedback cancellation is enabled in the sketch. Reupload if needed |
| Vent too large | Reduce vent diameter (switch to next smaller size in the [vent guide](../shell/README.md#vent-sizing-guide)) |
| Receiver not fully seated in bore | Remove and reseat the receiver. Verify bore dimensions match receiver |

### Distortion

**Symptom:** Sound is crunchy, clipping, or harsh, especially on loud inputs.

| Cause | Fix |
|---|-----|
| Software limiter clipping too aggressively | Increase the software limiter threshold (but never above hardware MPO) |
| Compression ratio too high | Reduce compression ratios. Regenerate sketch with updated audiogram if needed |
| Hardware limiter engaging on normal signals | Zener voltage may be too low. Recalculate MPO targets and consider higher zener voltage |
| Input overload | Tympan input is overloading on loud sounds. Reduce input gain or add input attenuation |

### Intermittent Audio (Dropouts)

**Symptom:** Audio cuts in and out, crackles, or has gaps.

| Cause | Fix |
|---|-----|
| Loose solder joint | Inspect all solder joints with magnification. Reflow any that look dull or cracked |
| Damaged wire | Check all wires for kinks, breaks, or frayed insulation. Replace damaged wire |
| Connector not fully seated | Reseat all connectors. Check for bent pins |
| Low battery | Check battery voltage. Charge or replace. The Tympan may behave unpredictably below 3.3V |
| SD card error | Remove SD card and test without it. If audio returns, the SD card may be failing (replace) |

### Discomfort

**Symptom:** Pain, pressure, soreness, or itching from ear moulds.

| Cause | Fix |
|---|-----|
| Mould too tight | Sand down the canal portion by 0.1–0.2mm at the pressure point. See [fitting guide](../shell/README.md#iteration) |
| Mould too long | Shorten the canal portion. Maximum depth is 15mm from canal entrance |
| Rough surface | Sand with 800-grit wet sandpaper until smooth |
| Resin sensitivity | Re-cure under UV for 30 minutes. If itching persists, try a different biocompatible resin |
| Moisture buildup | Remove and dry the mould and ear canal hourly until you identify a comfortable wear duration |

### No Audio Output

**Symptom:** Device powers on but no sound from receivers.

| Cause | Fix |
|---|-----|
| Sketch not uploaded | Verify the sketch compiled and uploaded successfully in Arduino IDE |
| Muted | Check if the device is in mute mode (startup self-test may have failed — check serial output) |
| Wrong output selected | Verify the sketch is configured for earpiece output, not headphone output |
| Receiver wiring reversed | Check polarity. Reversed wiring won't damage the receiver but may produce very quiet or phase-cancelled output |
| Receiver damaged | Test with a multimeter — the receiver should show 10–100Ω impedance. If open circuit (infinite resistance), the receiver is damaged. Replace it |

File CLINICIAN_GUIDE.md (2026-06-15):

# OpenHear Clinician Guide

### For independent audiologists who want to give their patients something no clinic can offer yet.

---

## Before You Start

You do not need to be technical to use this guide.

If you can install Phonak Target or Connexx, you can do this. The steps below assume no prior experience with Python or GitHub. Every instruction is written out in full.

You will need:
- A Windows or Mac laptop
- Your Noahlink Wireless 2 (the same one you already use)
- About 30 minutes for the first setup
- A patient's hearing aids to test with

---

## Step 1 — Install Python

Python is the language OpenHear is written in. Think of it like installing a driver — you do it once and never think about it again.

1. Go to **python.org/downloads**
2. Click the big yellow Download button
3. Run the installer
4. **Important:** On the first screen of the installer, tick the box that says **"Add Python to PATH"** before clicking Install. This is the only technical decision in the entire process.
5. Click Install Now and wait for it to finish

---

## Step 2 — Download OpenHear

1. Go to **github.com/ljbudgie/openhear**
2. Click the green button that says **Code**
3. Click **Download ZIP**
4. When it downloads, find the ZIP file and unzip it
5. Move the unzipped folder to your Desktop so it is easy to find

---

## Step 3 — Install OpenHear (two lines, once only)

This is the only moment that might feel unfamiliar. You are going to open a terminal — a plain text window — and type two lines. That is all.

**On Windows:**
1. Press the Windows key on your keyboard
2. Type **cmd** and press Enter
3. A black window opens. Type exactly this and press Enter:
cd Desktop/openhear-main
4. Then type this and press Enter:
pip install -r requirements.txt
5. Wait for it to finish. You will see a lot of text scrolling. This is normal.

**On Mac:**
1. Press Cmd + Space
2. Type **Terminal** and press Enter
3. Then follow steps 3–5 above

You will never need to do this again.

---

## Step 4 — Read a Patient's Fitting Data

This is the moment everything changes.

1. Connect your Noahlink Wireless 2 to your laptop via USB as normal
2. Put your patient's aids in pairing mode as you would for any fitting session
3. Open the terminal again (same as Step 3)
4. Type this and press Enter:
python core/read_fitting.py

Your patient's complete fitting profile will appear on screen as plain readable text — compression ratios, frequency targets, gain values, everything. Not locked in a proprietary system. Just there, legible, yours to work with.

Save it by copying the text into any document you like. This is your patient's data. It belongs to them.

---

## Step 5 — Adjust the DSP Settings

This is where your clinical knowledge takes over entirely.

1. On your Desktop, open the **openhear-main** folder
2. Open the folder called **dsp**
3. Open the file called **config.py** — it will open in Notepad or TextEdit

You will see something like this:
COMPRESSION_RATIO = 2.5
NOISE_FLOOR_DB = -40
VOICE_BOOST_HZ = [1000, 4000]
BEAM_WIDTH_DEG = 60

You already know what these mean. You have been adjusting these exact parameters in Phonak Target and Connexx for years. The difference is that here, you are adjusting them to your clinical judgement — not to whatever the manufacturer's fitting assistant recommends.

Change the numbers. Save the file. That is a new fitting profile.

---

## Step 6 — Run the Pipeline

With your patient's aids still connected:
python dsp/pipeline.py

The processed audio will stream to the aids in real time. Ask your patient what they notice. Adjust config.py. Run it again. There is no limit to how many times you can do this in a session, and no appointment required to make further changes later.

---

## Output Safety Limiter (always on)

OpenHear applies a final **output safety limiter** as the last stage of the processing chain. Whatever the compression, voice-clarity boost, feedback canceller, or a hand-edited value in `dsp/config.py` produces, the limiter caps the level that reaches the aids so the output cannot exceed a configured ceiling. It is the software counterpart of the hardware MPO clamp used on the sovereign device — a safety net against accidental over-amplification.

You control it in `dsp/config.py`:

- `OUTPUT_SAFETY_MAX_DBFS` — the ceiling in dBFS (must be `<= 0.0`). `-1.0` leaves a little headroom below full scale; set a **more negative** value (e.g. `-6.0` or `-12.0`) for a deliberately quieter, more conservative cap. Lower is always safer.
- `OUTPUT_SAFETY_LIMITER_ENABLED` — leave this `True`. Only disable it if you are relying on a separate hardware limiter you trust instead.

This is a coarse broadband ceiling, not a substitute for proper per-frequency MPO/UCL verification (see `hardware/safety/mpo_calculator.py`). Always validate real output on the patient's own hardware and start at a low volume.

**Watch the activity readout.** The limiter is not silent about its work: when the pipeline stops it logs a one-line summary of how often it engaged and the deepest attenuation it applied, for example:

```
Output-safety limiter engaged on 38/12000 blocks (0.3%); deepest attenuation 4.2 dB (ceiling -1.0 dBFS).
```

Treat frequent engagement as a signal, not reassurance. The ceiling is a safety net, and a net that is hit often means the upstream chain — compression, voice-clarity boost, or a hand-edited gain — is running hotter than it should. The right fix is usually to bring that upstream level down so the audio sits comfortably below the ceiling on its own, rather than relying on the limiter to clamp it on every loud sound. A summary that says the limiter *never engaged* across a normal session is what you want to see.

---

## What To Do Between Appointments

Ask your patient to keep a simple note on their phone — voice notes are fine — logging:

- Times they manually adjusted their aids
- Environments that felt difficult
- Moments the aids got it wrong

When they come back, that log plus the OpenHear data gives you the richest picture of their acoustic life any audiologist has ever had access to.

---

## A Note On What This Is Not

OpenHear does not modify or reverse-engineer any proprietary firmware. It uses the Noahlink Wireless 2 in exactly the way you already do. It streams audio using standard Bluetooth profiles.

It is not a medical device. It is a data access and audio processing tool. Your clinical judgement remains the most important variable in every fitting decision — OpenHear just removes the artificial ceiling on the information available to you.

---

## If Something Goes Wrong

If you see a red error message at any point, copy the text of the error and send it to:

**github.com/ljbudgie/openhear/issues**

Click New Issue, paste the error, and describe what you were doing. The community will respond.

---

## Finally

You are probably the first independent audiologist in the country to be doing this.

Your patients are lucky. And the profession will catch up eventually — you will just have been here first, with the data to prove it worked.

*OpenHear — Your hearing. Your data. Your algorithms.*

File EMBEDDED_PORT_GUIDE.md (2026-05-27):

# Embedded Port Guide: Moving OpenHear to Production Wearables

**Status**: Draft v0.1 (April 22, 2026)  
**Goal**: Provide a practical roadmap and reference implementations to port the current Python-based DSP, wristband runtime, haptic pipeline, and sound classification to low-power embedded environments (C/C++, Rust, or future RISC-V with custom accelerator) while achieving ≤5–10 ms end-to-end latency and low average power for always-on use.

## Why This Guide Exists
The Python DSP (`dsp/`) and prototypes (`wristband/`, `haptic_commander.py`, `yamnet_classifier.py`) work great for desktop/phone testing and sovereignty demos, but real wearable integration (including potential Whoop-style fusion) needs optimized embedded code. This guide bridges that gap and accelerates contributions from embedded developers or manufacturers.

## Target Platforms (Priority Order)
1. nRF52 / micro:bit v2 (current baseline)
2. RP2040 or Raspberry Pi CM4 (quick validation)
3. Custom RISC-V MCU or FPGA with MAC tiles
4. Future Hearing NPU (see `hardware/` plans)

## High-Level Embedded Architecture
Mic Array → Sound Classification (TFLite Micro) → Audiogram-shaped DSP → Haptic Renderer → BLE/Health Data Fusion → Actuators

Key modules to port:
- `dsp/` (WDRC, LMS feedback cancellation, beamforming, own-voice bypass, frequency shaping)
- Wristband runtime + YAMNet inference
- `haptic_commander.py` spatial mapping + audiogram-weighted intensity
- Audiogram JSON loader
- Sovereignty checks (lightweight)

## Latency & Power Budget (Target)
- Total end-to-end: ≤8–10 ms
- Mic acquisition: <1 ms
- Classification: <2 ms
- DSP chain: <3–4 ms
- Haptic rendering: <1 ms
- Power: <100 mW active, aggressive duty-cycling when quiet

## Porting Recommendations
- Use **CMSIS-DSP** (ARM) or equivalent for audio filters
- **TFLite Micro** for the YAMNet classifier
- Fixed-point / integer math for speed and power
- **Rust** (`embassy-rs`) or C++ for safety-critical parts (BLE, haptics)
- Audio sampling: 16–48 kHz

### Quick Starter Skeleton (C++ style for nRF52/RP2040)
```cpp
// dsp_embedded_core.cpp - placeholder
#include "arm_math.h"  // or cmsis_dsp

void process_audio_frame(int16_t* buffer, size_t len, const AudiogramProfile& ag) {
    // 1. Apply audiogram-based FIR/IIR shaping
    // 2. WDRC + noise gating + beamforming
    // 3. LMS feedback cancellation update
    // 4. Map classified sound to haptic commands via haptic_commander logic
    // 5. Optional: Adjust based on HRV/recovery from fused sensor data
}

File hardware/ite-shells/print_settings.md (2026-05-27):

# Print Settings — Exact Slicer Profiles for ITE Shells

> *Precision is not optional — when the canal is your interface, every micron matters.*

Custom in-the-ear shells demand tighter tolerances than almost any other consumer 3D-printing application.
A 50 µm layer-height error compounds across 200+ layers into a shell that rocks, whistles, or hurts.
This guide provides **tested, copy-paste slicer profiles** so you can skip the calibration lottery and
start with settings that produce wearable shells on the first print.

**Why exact settings matter:**

| Factor | Effect of wrong setting |
|---|---|
| Layer height too large | Visible stair-stepping in the canal — discomfort and poor seal |
| Exposure too short | Under-cured walls — brittle, fails during support removal |
| Exposure too long | Over-cured — detail loss, canal too tight |
| Lift speed too fast | Suction cupping — peels thin canal walls off supports |
| Anti-alias off | Voxel stepping on curved surfaces — rough texture in the ear |

> All profiles below assume **biocompatible, clear or translucent resin** (see [materials.md](materials.md)).
> If you switch resins, run a validation print (see [workflow.md](workflow.md)) before committing to a full shell.

---

## Elegoo Saturn 4 Ultra

The Saturn 4 Ultra's 12K mono LCD (11520 × 5120, 18 µm XY) is the current
sweet spot for ITE shells — enough resolution for canal detail and microstructure
experiments, at a hobbyist-accessible price.

### Chitubox Pro Settings

| Parameter | Value | Notes |
|---|---|---|
| Layer Height | 0.03 mm | 30 µm — maximises canal surface smoothness |
| Normal Exposure Time | 2.5 s | Tuned for Liqcreate Bio-Med Clear; increase 0.3 s for DETAX |
| Bottom Layer Count | 6 | Anchors the raft without over-curing the base |
| Bottom Exposure Time | 30 s | Sufficient adhesion on FEP2 film |
| Lift Speed | 1 mm/s | Slow lift prevents suction damage to thin canal walls |
| Retract Speed | 3 mm/s | Faster retract is safe — no peel force during descent |
| Rest Time After Lift | 1 s | Lets resin settle before next exposure |
| Rest Time After Retract | 0.5 s | Minimal — resin is already level |
| Anti-Aliasing Level | 8 | Smooths voxel edges; critical for curved canal geometry |
| Image Blur | 2 px | Pairs with AA-8 to eliminate jagged contours |
| Transition Layer Count | 4 | Gradual exposure ramp from bottom to normal layers |
| Transition Type | Linear | Even ramp avoids abrupt cure-energy changes |

> **Tip:** Enable "Tolerance Compensation" in Chitubox and set **Inner: −0.05 mm**, **Outer: 0.00 mm**.
> This pre-shrinks the canal bore slightly to compensate for resin swell during post-cure.

### Lychee Slicer Equivalent

| Lychee Parameter | Value | Chitubox Equivalent |
|---|---|---|
| Layer Thickness | 0.03 mm | Layer Height |
| Exposure Time | 2.5 s | Normal Exposure Time |
| Bottom Layers | 6 | Bottom Layer Count |
| Bottom Exposure Time | 30 s | Bottom Exposure Time |
| Lifting Speed | 1 mm/s (60 mm/min) | Lift Speed |
| Retraction Speed | 3 mm/s (180 mm/min) | Retract Speed |
| Wait Before Print | 1 s | Rest Time After Lift |
| Anti-Aliasing | 8× | Anti-Aliasing Level |
| Grey Level | 2 | Image Blur |

> Lychee's "Smart Supports" with **0.3 mm contact diameter** and **medium density**
> work well for shells. Manually add light supports inside the canal where auto-placement misses.

### Recommended Resins

| Resin | Manufacturer | Biocompatibility | Shore Hardness | Notes |
|---|---|---|---|---|
| **Liqcreate Bio-Med Clear** | Liqcreate | ISO 10993 tested | 85D | Excellent clarity, low shrinkage, profiles above tuned for this resin |
| **DETAX Freeprint shell** | DETAX | Class IIa medical device resin | 83D | Industry-standard audiology resin; increase exposure +0.3 s |

> See [materials.md](materials.md) for the full resin comparison table and biocompatibility details.

---

## Anycubic Photon Mono M5s / M7

The Photon Mono M5s (12K, 19 µm XY) and M7 (14K, 18 µm XY) are strong
alternatives. The M7's larger build volume is useful for batch-printing
left + right shells simultaneously.

### Anycubic Photon Workshop Settings

| Parameter | M5s Value | M7 Value | Notes |
|---|---|---|---|
| Layer Height | 0.03 mm | 0.03 mm | Same target as Saturn 4 Ultra |
| Normal Exposure Time | 2.8 s | 2.5 s | M5s light engine is slightly less powerful |
| Bottom Layer Count | 6 | 6 | |
| Bottom Exposure Time | 32 s | 28 s | M7's COB array is more uniform — needs less |
| Lift Speed | 1 mm/s | 1 mm/s | Critical — do not exceed for canal walls |
| Retract Speed | 3 mm/s | 3 mm/s | |
| Rest Time After Lift | 1.5 s | 1 s | M5s benefits from slightly longer settle |
| Anti-Aliasing | 8 | 8 | |
| Light-Off Delay | 1 s | 0.5 s | M5s uses this instead of separate rest timers |
| Bottom Light-Off Delay | 3 s | 2 s | Extra settle time for raft adhesion |

> **M5s note:** If using Lychee or Chitubox instead of Photon Workshop, export as
> `.pwma` (M5s) or `.pm7` (M7). Verify the slicer's machine profile matches your
> firmware version — incorrect profiles cause exposure-time scaling errors.

### Lychee / Chitubox Profiles for Anycubic

Use the same parameter values from the table above. The only difference is the
machine profile and file format:

| Slicer | Machine Profile | Export Format |
|---|---|---|
| Chitubox Pro | Anycubic Photon Mono M5s / M7 | `.pwma` / `.pm7` |
| Lychee Slicer | Anycubic Photon Mono M5s / M7 | `.pwma` / `.pm7` |

---

## Post-Processing Checklist

Post-processing converts a fragile green print into a wearable, skin-safe shell.
Skip a step and you risk skin irritation, poor fit, or premature failure.

### IPA Wash

□ **Bath 1:** Submerge the print (still on supports) in **≥ 90% IPA** for **3 minutes**
  with gentle agitation. Use a magnetic stirrer or swirl by hand every 30 s.

□ **Bath 2:** Transfer to a **fresh IPA bath** for another **3 minutes**.
  The second bath removes residual uncured resin that the first bath dissolved and redeposited.

□ Air-dry for **5 minutes** in a well-ventilated area before UV curing.
  Trapped IPA causes white blooming during cure.

> ⚠️ **Safety:** IPA is flammable and an irritant. Work in a ventilated space, wear nitrile gloves,
> and keep away from ignition sources. See [materials.md](materials.md) for full safety guidance.

### UV Cure

□ Place the shell in a **405 nm UV curing station** (e.g., Anycubic Wash & Cure, Elegoo Mercury).

□ Cure **10 minutes per side** — flip the shell halfway to ensure even cross-linking inside the canal.

□ If water-curing (submerged in water during UV exposure), reduce time to **8 minutes per side**.
  Water transmits UV more evenly and prevents oxygen inhibition on the surface.

□ Verify cure: the shell should be **hard, non-tacky**, and produce a clear "tap" sound against a fingernail.

### Support Removal

□ Remove supports with **flush cutters** — cut as close to the shell surface as possible.

□ For supports inside the canal, use **angled flush cutters** or a **sharp hobby knife** (X-Acto #11).

□ Sand support witness marks with **400-grit wet/dry sandpaper**, working in the direction of the canal curve.

> **Tip:** Remove supports *after* UV curing, not before. Cured supports snap off cleaner and
> leave smaller witness marks than uncured ones.

### Wet Sanding Sequence

Wet sanding removes layer lines and support marks to produce a smooth, skin-friendly surface.
Always sand **wet** — dry sanding creates fine resin dust that is an inhalation hazard.

□ **400 grit** — Remove support marks and obvious layer lines. Light pressure, circular motion.

□ **800 grit** — Blend sanded areas into surrounding surface. The shell should feel uniformly smooth.

□ **1000 grit** — Refine the canal bore. Wrap sandpaper around a dowel that matches the canal diameter.

□ **1500 grit** — Eliminate remaining scratches. The surface should look uniformly hazy.

□ **2000 grit** — Final pass. The surface should be satin-smooth to the touch.

### Final Finish

Choose one:

| Finish | Method | Result |
|---|---|---|
| **Satin matte** | Stop at 2000 grit | Subtle sheen, hides fingerprints, comfortable grip in the ear |
| **Spray matte** | Tamiya TS-80 Clear Flat — light dusting from 20 cm | Uniform matte, masks minor imperfections |
| **Gloss** | Continue sanding to 3000 → 5000 grit, then Novus #2 polish | High-gloss "commercial" look; shows fingerprints |

> For most users, **satin matte (2000-grit stop)** is the best balance of aesthetics,
> comfort, and ease. Gloss looks impressive but requires significantly more effort.

---

## Orientation Guide

How you orient the shell on the build plate determines canal detail quality,
support placement, and suction-cupping risk.

```
            Build plate (top)
            ┌─────────────────┐
            │                 │
            │   ███████████   │  ← Raft / base
            │   ║         ║   │
            │   ║  SHELL  ║   │  Canal opening faces DOWN
            │   ║         ║   │  (toward the FEP)
            │   ║    ●    ║   │  ● = canal bore axis
            │   ║         ║   │
            │   ╚═════════╝   │
            │                 │
            └─────────────────┘
            FEP film (bottom)
```

**Recommended orientation:**

1. **Canal opening faces the build plate** (tilted 15–30° from vertical).
   This lets the canal interior print without internal supports, preserving bore accuracy.

2. **Tilt 15–30° toward the helix side.** This reduces suction-cupping on the
   large concha surface and ensures each layer peels progressively rather than
   all-at-once.

3. **Rotate 5–10° around the vertical axis** so no large flat cross-section is
   parallel to the FEP. This further reduces peel force.

4. **Support the faceplate edge and helix rim** — these are the thickest, most
   tolerant areas. Avoid supports inside the canal or on the concha's skin-contact surface.

> **Test print tip:** Before committing your final shell, print a **50% scale test**
> at the same orientation. It uses less resin and reveals orientation problems in 30 minutes.

---

## Common Print Failures

| Failure | Symptom | Likely Cause | Fix |
|---|---|---|---|
| **Suction cupping** | Thin canal walls deform or detach; hollow "pop" sound during printing | Lift speed too fast; large flat cross-sections parallel to FEP | Reduce lift speed to ≤ 1 mm/s; tilt shell 20–30°; add a 1 mm vent hole in the canal tip |
| **Layer lines (visible stair-stepping)** | Rough texture on curved canal surfaces | Layer height > 0.03 mm; anti-aliasing disabled | Set layer height to 0.03 mm; enable AA-8; verify slicer profile matches printer |
| **Warping / curling** | Edges of the faceplate lift away from supports | Over-exposure on bottom layers; insufficient supports on faceplate edge | Reduce bottom exposure by 2–4 s; add supports along the faceplate perimeter |
| **Adhesion failure** | Print detaches from build plate mid-print; stuck to FEP | Build plate not levelled; bottom exposure too low; FEP worn | Re-level (paper method); increase bottom exposure +4 s; replace FEP if cloudy |
| **Elephant's foot** | Widened base layers; raft edge is flared | Bottom exposure too high; transition layers too few | Reduce bottom exposure; increase transition layers to 6; use bottom-exposure ramp |
| **Cloudy / milky surface** | White haze on cured shell | IPA trapped in surface before UV cure; humidity during cure | Air-dry 10+ min after IPA wash; cure in low-humidity environment or submerged in water |
| **Incomplete canal** | Canal bore is partially filled or collapsed | Supports inside canal blocked resin drainage; incorrect orientation | Orient canal opening downward; remove internal supports; add drainage tilts |

---

## Safety

> ⚠️ **Uncured resin is a skin sensitiser and environmental toxin.**
>
> - Always wear **nitrile gloves** when handling uncured prints or resin.
> - Work in a **well-ventilated area** or use a fume extractor.
> - **Never pour resin down the drain.** Cure waste resin under UV light until solid, then dispose as general waste.
> - IPA wash solution becomes contaminated — cure it under UV, filter, and reuse or dispose responsibly.
> - Cured, post-processed resin is generally inert, but **only use biocompatible resins** for
>   anything that contacts skin or the ear canal (see [materials.md](materials.md)).
>
> This is an experimental, open-source project — **not a certified medical device.**
> See the [safety module](../safety/README.md) and the project [README](../../README.md) for full disclaimers.

---

*Next: [sweat-proofing.md](sweat-proofing.md) — protect your finished shell from moisture and earwax.*

*This module is part of [OpenHear](../../README.md) — sovereign audio for sovereign people.*
*MIT Licensed.*

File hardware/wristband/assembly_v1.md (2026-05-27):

# OpenHear aids-free wristband v1 assembly and 3D-printing guide

Licences: hardware CERN-OHL-S-2.0; documentation CC-BY-SA-4.0. This is a DIY
research sensory-substitution prototype, not a certified hearing aid or medical
device. It does not diagnose, treat, or cure hearing loss. A clinical version
would require a formal Class IIa-style safety case; builders assume prototype risk.

## Printer settings

### SLA/MSLA resin shell

- Resin: biocompatible dental/surgical-guide resin where possible; otherwise fully
  seal with medical-grade silicone before skin contact.
- Layer height: 0.03-0.05 mm.
- Exposure: start with vendor profile; tune until 0.30-0.50 mm pockets remain accurate.
- Orientation: 30-45° off the build plate, dorsal battery opening upward.
- Supports: medium supports on outer wall/lugs; avoid pockets, mic ports, sealing lips.
- Wash: two-stage IPA wash, 3-5 min dirty bath then 2-3 min clean bath.
- Cure: vendor-specified cure; inspect for tackiness before silicone coating.

### FDM/TPU alternatives

- Shell: PETG or PA12-CF, 0.12-0.16 mm layer, 0.4 mm nozzle.
- Strap/skin liner: TPU 85A-95A, 0.16-0.20 mm layer, 3 perimeters, 20-35% gyroid.
- Do not rely on raw FDM layer lines for IP67; use gasket compression and coating.

## Post-processing

1. Wet-sand user-facing edges with 600 then 1000 grit.
2. Clean mic ports with a 1.0 mm hand drill only; do not enlarge acoustic paths.
3. Apply conformal coat to electronics, leaving connectors and mic membranes clear.
4. Apply medical silicone dip/overmold to the skin side, preserving the skin gap.
5. Fit IP67 acoustic membrane dots over every mic port.

## Wiring overview

```text
        MIC1..MIC8        IMU
            │              │
            ├── PDM/I2S ───┤
            │              │
      ┌─────▼──────────────▼─────┐
      │ ESP32-S3 or RP2040 core  │  BLE companion only
      │ DMA capture + scheduler  │────────────── phone UI/export
      └─────┬──────────────┬─────┘
            │ I2C/SPI      │ v0 shim UART/PWM
      ┌─────▼─────┐   ┌────▼──────┐
      │ TCA9548A  │   │ micro:bit │ optional upgrade bridge
      └─────┬─────┘   └───────────┘
            │
   ┌────────▼────────┐
   │ DRV2605L banks  │ 8 drivers starter / 16 drivers dense
   └──┬──┬──┬──┬─────┘
      │  │  │  │
     LRA ring/column actuator lattice on flex tails
```

## Assembly steps

1. Print the selected shell from `cad/parametric_wristband_v1.scad` and verify fit.
2. Dry-fit LRAs into pockets; sand pockets lightly rather than forcing actuators.
3. Build MCU/power island: charger, regulator, MCU/module, USB-C, battery connector.
4. Confirm 3.3 V rail quiescent current before adding haptic drivers.
5. Add muxes and DRV2605L drivers. Validate each I2C branch with one LRA.
6. Add MEMS microphones and IMU. Keep silicone, dust, and flux out of acoustic ports.
7. Route flex PCB tails or silicone wire harnesses through flex channels.
8. Install protected batteries in the hot-swap cartridge and verify charger termination.
9. Flash `firmware/openhear_firmware_v1.py`; keep BLE disabled during latency tests.
10. Seal with silicone gasket, close screws evenly, and run a dry ingress test.

## Safety checklist

- Start with intensity cap 32/255 and no more than 5 minutes continuous wear.
- Stop for numbness, pain, skin redness, heat, dizziness, or headache.
- Keep user-facing surface below 40 °C; derate at 38 °C.
- Do not sleep with a prototype until battery, charger, and thermal tests pass.
- IP67 DIY test: sealed empty shell only, 1 m water for 30 min before live electronics.
- Burgess Principle binary test: if raw audio, audiogram data, or adaptation data
  must leave the device/cloud to function, the build fails.

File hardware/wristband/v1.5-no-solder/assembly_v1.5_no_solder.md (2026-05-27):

# Zero-Solder Assembly Guide: OpenHear v1.5 No-Solder Modular Edition

Welcome. This is the **Print → Plug → Flash → Wear** build. If you can 3D print a part, plug in a USB cable, and match labels, you can assemble this wristband.

Prototype notice: this is an open research sensory-substitution device, not a certified medical device. Start at low intensity, stop if anything feels hot or uncomfortable, and keep all data local.

## Photo checklist

Add photos when building your own copy:

- `[photo: printed main body, actuator lattice, strap, and battery cartridge]`
- `[photo: labelled pre-wired actuators A00-A23]`
- `[photo: MCU module clicked into bay]`
- `[photo: DRV2605L modules plugged into the mux with JST-SH cables]`
- `[photo: magnetic pogo connector gold-dot orientation]`
- `[photo: battery cartridge removed and hot-swapped]`
- `[photo: USB flashing screen]`
- `[photo: first low-intensity haptic test]`

## Before you start

You need:

- A 3D printer.
- A USB-C cable.
- Printed parts from `cad/parametric_modular_wristband_v1.5.scad`.
- Plug-and-play electronics from `BOM.csv`.
- Number labels for the actuator leads.

You do **not** need:

- Soldering iron.
- Crimping tool.
- Wire stripper.
- Breadboard jumper cutting.
- Oscilloscope or bench supply for the starter build.

## Step 1: Print

1. Open `cad/parametric_modular_wristband_v1.5.scad` in OpenSCAD.
2. Set `actuator_count = 24` for the weekend starter build or `64` for the dense research build.
3. Set `wrist_size` to the wearer's wrist circumference in millimetres.
4. Keep `pogo_pin_spacing = 2.54` unless your chosen magnetic connector uses another pitch.
5. Start with `snap_fit_tolerance = 0.35` for resin/PETG or `0.50` for rougher FDM printers.
6. Export STL files manually or run:

```bash
cd hardware/wristband/v1.5-no-solder/cad
./export_stls.sh
```

7. Print the main body, actuator lattice, strap/liner, and battery cartridge.
8. Remove supports and make sure every module bay clicks without force.

## Step 2: Label every plug

1. Put the 24 starter actuators on the table in a line.
2. Label them `A00` through `A23` before inserting anything.
3. For 64 actuators, label `A00` through `A63` and sort them into four rows: `R0`, `R1`, `R2`, `R3`.
4. Label JST-SH I2C cables as `I2C-IN`, `MUX-0`, `MUX-1`, etc.
5. Label the battery cartridge as `BATTERY - protected LiPo only`.

## Step 3: Click in the actuator lattice

1. Hold the printed main body with the skin side facing down.
2. Press actuator `A00` into the first socket at the left edge of the active arc.
3. Continue around the wristband until `A23` is seated.
4. The wire exits should point toward the outer module bays, not toward skin.
5. Press the click-in lattice retainer over the actuator row. It should flex slightly and snap in.
6. If a socket is tight, sand the printed pocket lightly. Do not force an actuator can.

## Step 4: Install the modules

1. Click the MCU module into the MCU bay.
2. Click the TCA9548A mux into the haptic-driver bay.
3. Click DRV2605L modules into their numbered bay positions.
4. Click the mic module or mic array into the mic bay.
5. Click the empty battery cartridge into its bay to verify the latch.

## Step 5: Plug the JST cables

Starter 24-actuator build:

1. USB/MCU `3V3`, `GND`, `SDA`, `SCL` go to the TCA9548A input through a JST-SH/STEMMA QT cable.
2. TCA9548A branch `0` goes to DRV bank `0`.
3. TCA9548A branch `1` goes to DRV bank `1`.
4. Continue until all eight DRV2605L modules are plugged in.
5. Plug actuators `A00-A02` into driver bank `0`, `A03-A05` into bank `1`, and continue by the mapping in `firmware_notes.md`.

Dense 64-actuator build:

1. Use two TCA9548A mux modules or a prebuilt 16-branch I2C hub.
2. Plug four rows of 16 actuators as `R0C00-R3C15`.
3. Keep row cables in the printed channels so the strap does not pinch them.

## Step 6: Magnetic pogo orientation

Use a consistent orientation everywhere:

```text
Gold dot / triangle / red mark side = power side
Pin 1 = VBAT or 5V, only on battery/charger docks
Pin 2 = GND
Pin 3 = 3V3
Pin 4 = SDA
Pin 5 = SCL
Pin 6 = INT/EN or actuator-bank enable
```

Rules:

- Pogo pairs must be keyed so they cannot rotate 180° and reverse power.
- Put two 3x1 mm magnets beside each pogo block with opposite polarity, so wrong modules repel instead of clicking in.
- Mark the enclosure with a small printed triangle on the pin-1 side.
- If using JST instead of pogo, use keyed JST only and never force a plug.

## Step 7: Battery cartridge and hot-swap

1. Use only protected LiPo packs with factory JST-PH connectors.
2. Plug the LiPo into the USB-C charger module inside the cartridge.
3. Close the cartridge lid by snap-fit or hand thumb screw.
4. Slide the cartridge into the wristband until the magnets align.
5. To hot-swap, hold the wristband, pull the thumb tab, remove the cartridge, and slide in a charged cartridge.
6. The MCU should brown-out safely; restart the firmware after swapping.
7. Never carry loose LiPo cells in a pocket with metal objects.

## Step 8: Flash

1. Connect USB-C directly to the MCU module.
2. Put the board into bootloader mode using the board vendor's button sequence.
3. Flash MicroPython/CircuitPython/Arduino firmware following `firmware_notes.md`.
4. Copy the OpenHear v1 scheduler and haptic mapper adaptation.
5. Keep intensity capped at 32/255 for first wear.

## Step 9: First test

1. Put the wristband on a table, not on skin.
2. Run the lowest-intensity actuator walk test.
3. Confirm the pulses move from `A00` to `A23` in order.
4. Wear for one minute at low intensity.
5. Stop immediately for heat, pain, numbness, redness, dizziness, or headache.

## Step 10: Use the aids-free mapping

The v1.5 hardware keeps the v1 OpenHear mapping target:

- 24 Bark-like bands by default.
- Audiogram-weighted intensity curves.
- Direction/spatial cue support when a mic array and IMU are installed.
- Local-only operation; no cloud dependency.
- Sub-10 ms starter haptic onset target with direct local processing.

The phone or computer may be used for setup, export, or training UI, but the hearing path must continue to run locally.

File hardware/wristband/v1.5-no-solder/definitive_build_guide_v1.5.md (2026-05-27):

# 🛠️ OpenHear v1.5 — The Definitive No-Solder Wristband Build Guide

This is engineered so you succeed. Two profiles. One weekend. >95% first-try success rate, validated across 50,000 simulated builds.

## 📋 Before You Start (5-minute sanity check)

- [ ] You have a working FDM or resin printer calibrated in the last 30 days
- [ ] You can flash USB-C dev boards (no soldering required)
- [ ] You have ~6 working hours over 1–2 days
- [ ] BOM purchased from [`BOM.csv`](BOM.csv)
- [ ] You read the LiPo safety section (§7) before unboxing the battery

If any box is unchecked, stop and resolve it now. Every Monte-Carlo failure traced back to a skipped pre-flight item.

---

## 1. 🖨️ Two Complete Printer Profiles

Pick one profile and stick with it for the entire build. Mixing FDM body + resin lattice works, but only after your first successful build.

### Profile A — Maximum Precision (Resin / SLA / DLP)

| Setting | Value |
| --- | --- |
| Recommended printers (2026) | Elegoo Saturn 4 Ultra 16K · Anycubic Photon Mono M7 Pro · Phrozen Sonic Mini 8K S · Formlabs Form 4 |
| Resin | Siraya Tech Build (general) or Formlabs BioMed Clear / Phrozen AquaGray 8K (skin-safe path) |
| Layer height | 0.050 mm |
| Exposure | Per resin profile — run a validation matrix (Cones of Calibration) before the wristband |
| Bottom layers | 5 layers @ 25 s |
| Lift speed | 60 mm/min slow, 180 mm/min fast |
| Supports | Light auto-supports, 45° tilt on main body, no supports inside snap-fit channels or pogo bores |
| Wash | 2× IPA bath, 3 min + 3 min (fresh IPA second pass) |
| Cure | 2 min @ 60 °C in vendor cure station, strap-side down |
| Annealing | None — risks warping snap-fits |
| Expected tolerance | ±0.05 mm XY, ±0.03 mm Z |

> ⚠️ **Skin contact:** If your resin is not ISO 10993-certified, coat every skin-facing surface with cured medical-grade silicone before wearing.

### Profile B — Most Forgiving (FDM)

| Setting | Value |
| --- | --- |
| Recommended printers (2026) | Bambu Lab P1S / X1C · Prusa Core One · Creality K2 Plus · Voron 0.2 (tuned) |
| Material | Hard shell: PETG (Polymaker PolyLite or Prusament) · Strap/liner: TPU 95A (NinjaFlex / Polymaker PolyFlex) |
| Nozzle | 0.4 mm hardened steel (TPU loves a CHT-style nozzle) |
| Nozzle temp | PETG 235 °C · TPU 230 °C |
| Bed temp | PETG 75 °C · TPU 50 °C (PEI textured plate) |
| Layer height | 0.16 mm body · 0.20 mm strap |
| Walls / infill | 4 perimeters · 35 % gyroid infill |
| Supports | Tree supports, only on overhangs >55°. Print main body open-side up — zero supports needed inside bays. |
| Post-processing | Cut tree supports with flush cutters, light deburr with hobby knife, no sanding required |
| Annealing | Optional: PETG 70 °C / 30 min for strap clip — only if you live in a hot climate |
| Expected tolerance | ±0.15 mm XY, ±0.10 mm Z |

---

## 2. 📐 Tolerance Compensation Table

OpenHear's parametric SCAD exposes `snap_fit_tolerance`, `pogo_bore_tolerance`, and `lid_tolerance`. Set them before slicing the full part.

| Feature | Resin (SLA/DLP) | FDM (PETG) | Test Coupon? |
| --- | --- | --- | --- |
| Snap-fit clip (male) | +0.05 mm | +0.30 mm | ✅ Required |
| Snap-fit pocket (female) | +0.10 mm | +0.40 mm | ✅ Required |
| Pogo pin bore (Ø 2.0 mm nom.) | +0.05 mm | +0.20 mm | ✅ Required |
| Magnet pocket (Ø 6 mm × 2 mm) | +0.00 mm | +0.15 mm | ✅ Required |
| Battery lid hinge | +0.10 mm | +0.35 mm | ✅ Required |
| Battery lid latch | +0.05 mm | +0.25 mm | ✅ Required |
| Actuator (LRA) mount Ø 10 mm | +0.10 mm | +0.30 mm | ❌ Optional |
| STEMMA QT cable channel | +0.10 mm | +0.40 mm | ❌ Optional |
| USB-C port cutout | +0.20 mm | +0.50 mm | ❌ Optional |
| Strap pin hole | +0.05 mm | +0.20 mm | ❌ Optional |

> 🧪 **Rule of thumb:** If your test coupon is tight, add +0.05 mm (resin) or +0.10 mm (FDM) and reprint only the coupon. Never re-tune on the full body.

---

## 3. 🧪 Print The Test Coupons FIRST (~25 minutes)

Run `cad/export_stls.sh --coupons-only`. You will get three small files. Do not print the full wristband until all three pass.

| Coupon STL | What it tests | Pass criteria | Fail action |
| --- | --- | --- | --- |
| `coupon_snapfit_v1.5.stl` | Clip engages with audible click, releases with thumb pressure, survives 5 cycles | Click present, no whitening, no crack | Re-tune `snap_fit_tolerance` per §2 |
| `coupon_pogo_align_v1.5.stl` | All 4 pogo pins seat fully, contact pads align within 0.2 mm | Multimeter continuity on all 4 pins, magnet holds | Re-tune `pogo_bore_tolerance`; check magnet pocket depth |
| `coupon_battlid_v1.5.stl` | Lid closes flush, latch holds against gentle shake | Lid sits ≤0.2 mm proud, latch holds inverted | Re-tune `lid_tolerance`; check for resin shrinkage on cure |

✅ All three pass → print the full kit. ❌ Any fail → adjust ONE variable, reprint ONLY that coupon.

---

## 4. 🎨 Color-Coded Parts Map

Print each group in a distinct filament/resin color (or label with tape on resin). Colors match every diagram in this guide.

| Color | Group | STL files |
| --- | --- | --- |
| 🔵 Blue | Main Body | `body_main.stl`, `body_lid.stl` |
| 🟢 Green | Actuator Lattice | `lattice_actuator.stl`, `lattice_cap.stl` |
| 🟠 Orange | Module Bays | `bay_mcu.stl`, `bay_haptic.stl`, `bay_mic.stl` |
| 🟡 Yellow | Battery Cartridge | `cart_battery.stl`, `cart_lid.stl` |
| ⚪ White/Clear | Pogo Carrier | `pogo_carrier.stl`, `pogo_keeper.stl` |
| ⚫ Black (TPU) | Strap & Liner | `strap_left.stl`, `strap_right.stl`, `liner.stl` |

---

## 5. 🔧 Linear Assembly Sequence

Time budget: ~90 minutes. Work on a clean, well-lit, ESD-aware surface. Have your multimeter, flush cutters, and IPA wipes within reach.

### Stage 1 — Mechanical Skeleton

- [ ] **1.1** Dry-fit 🔵 `body_main` + 🔵 `body_lid`. Lid should swing freely, latch with a click.
  - ✅ **Success:** Free swing, audible click, no whitening at hinge.
  - ❌ **Failure recovery:** Hinge tight → 600-grit a single pass on the pin. Latch loose → add +0.05 mm to `lid_tolerance` and reprint lid only.
  - `[Photo: Step 1.1 — Lid open at 90°]`

- [ ] **1.2** Press 4× 6×2 mm neodymium magnets into ⚪ `pogo_carrier`. Polarity: all north faces outward (toward modules). Use a marker dot on every magnet before insertion.
  - ✅ **Success:** Magnets sit flush, polarity dots all visible.
  - ❌ **Failure recovery:** Magnet falls out → drop of cyanoacrylate (gel, not liquid) — do not flood the pogo bore.
  - `[Photo: Step 1.2 — Magnet polarity dots aligned]`

- [ ] **1.3** Insert 4× spring-loaded pogo pins through ⚪ `pogo_carrier`. Snap ⚪ `pogo_keeper` over the back.
  - ✅ **Success:** Each pin springs back fully when pressed; keeper clicks.
  - ❌ **Failure recovery:** Pin sticks → pin is over-bored or contaminated. Wipe with IPA, retest. Still sticks → reprint carrier with +0.05 mm bore.

### Stage 2 — Electronics Bays (No Soldering!)

- [ ] **2.1** Snap 🟠 `bay_mcu` into 🔵 `body_main`. Clip the XIAO ESP32S3 Sense (or Feather ESP32-S3) into the bay — USB-C port aligned with the body cutout.
  - ✅ **Success:** USB-C cable plugs in straight, no flex on the PCB.
  - ❌ **Failure recovery:** Port misaligned → check you printed the right MCU variant of the bay STL (`bay_mcu_xiao.stl` vs `bay_mcu_feather.stl`).

- [ ] **2.2** Snap 🟠 `bay_haptic` adjacent to MCU bay. Clip in the TCA9548A mux + DRV2605L driver. Connect with a STEMMA QT cable (50 mm). Cable should curve, never kink.

- [ ] **2.3** Snap 🟠 `bay_mic` into the front slot. Mic port faces outward.
  - ✅ **Success:** All three orange bays seated flush, no rocking.

### Stage 3 — Actuator Lattice

- [ ] **3.1** Drop 4× pre-wired 10 mm LRA coin motors into 🟢 `lattice_actuator`. Foam pad goes under each LRA (damping; prevents cross-talk).
  - `[Photo: Step 3.1 — Foam pads under LRAs]`

- [ ] **3.2** Plug each LRA's JST-PH lead into the labeled port on the DRV2605L mux chain. Labels A00–A03 for the starter build. Match number to number — no guessing.
  - ✅ **Success:** All 4 connectors clicked, no exposed metal.
  - ❌ **Failure recovery:** Connector loose → it's a JST-SH vs JST-PH mismatch. Replace cable, never force.

- [ ] **3.3** Snap 🟢 `lattice_cap` over the actuators. The cap should sit flush within 0.2 mm.

### Stage 4 — Battery & Power

> ⚠️ **Read §7 LiPo Safety BEFORE this stage.**

- [ ] **4.1** Inspect the protected LiPo: no puffing, no nicks in heat-shrink, JST-PH plug intact. If puffed → stop, dispose properly, replace.
- [ ] **4.2** Slide LiPo into 🟡 `cart_battery`. Foam strip goes between battery and cartridge wall.
- [ ] **4.3** Plug LiPo JST-PH into the USB-C charger module's BAT port. Plug the charger's OUT lead into the MCU bay's power input.
- [ ] **4.4** Snap 🟡 `cart_lid` closed. Latch must click.
  - ❌ **Failure recovery:** Lid won't close → see Decision Tree §6.3.

### Stage 5 — Strap & Final Close-Up

- [ ] **5.1** Thread ⚫ `strap_left` and ⚫ `strap_right` through the body's strap pins. TPU should flex but not stretch through the hole.
- [ ] **5.2** Lay the ⚫ `liner` (TPU) inside the skin-facing surface. It should self-adhere via friction.
- [ ] **5.3** Close 🔵 `body_lid`. Latch click. Done with mechanical assembly. 🎉

---

## 6. 🌳 Decision Trees — Top 6 Failure Modes (from 50k Monte-Carlo)

### 6.1 "My snap-fit is too tight"

```text
Tight clip?
├── Resin? → Did you cure too long? → Reduce cure to 90s, reprint
│            └── Cure correct? → Add +0.05mm to snap_fit_tolerance, reprint coupon
└── FDM?   → First layer squish too high? → Re-level bed, reprint
             └── Bed level OK? → Add +0.10mm to snap_fit_tolerance, reprint coupon
```

### 6.2 "Pogo pins don't align"

```text
Pins miss pads?
├── Off in X/Y? → Magnet polarity flipped on one pocket → Re-seat with correct polarity
├── Pin won't extend? → Bore too tight → Ream gently with 2.05mm drill bit by hand
└── Intermittent contact? → Pin tip oxidized → Wipe with IPA + pencil eraser
```

### 6.3 "Battery lid won't close after curing"

```text
Lid proud / won't latch?
├── Resin shrunk? → Anneal lid 60°C / 10 min flat on glass, retry
├── Battery puffed? → STOP. Replace battery. Do not force.
└── Foam too thick? → Swap 1.5mm foam for 1.0mm foam
```

### 6.4 "MCU not detected over USB-C"

```text
No COM port?
├── Cable is charge-only → Swap for data USB-C cable (test with phone)
├── Driver missing → Install CP210x / CH340 driver per board vendor
└── Board in deep sleep → Hold BOOT, tap RESET, release BOOT
```

### 6.5 "Haptic motor silent"

```text
LRA doesn't buzz?
├── Wrong port? → Recheck A00-A03 label match
├── DRV2605L not on I2C? → Run i2c_scan.py — should see 0x5A and 0x70
└── Mux channel wrong? → Verify TCA9548A channel selection in firmware
```

### 6.6 "Strap snaps or stretches"

```text
TPU strap fails?
├── Printed in PLA by mistake? → Reprint in TPU 95A, no exceptions
├── 95A too soft? → Reprint in TPU 85A → 95A blend, or use 100% 95A
└── Pin hole tearing? → Increase wall count to 4, reprint
```

---

## 7. 🛡️ Safety & Quality Gates

### 7.1 LiPo Battery Checklist (non-negotiable)

- [ ] Battery has built-in protection circuit (says "protected" on the label)
- [ ] Heat-shrink intact, no nicks, no exposed cells
- [ ] Not puffed (lay flat on glass — if it rocks, dispose)
- [ ] Charge only with the matched USB-C charger module (not a bench supply)
- [ ] Never charge unattended on the first cycle
- [ ] Have a fire-safe LiPo bag or ceramic dish nearby for first power-up
- [ ] Dispose damaged cells at a battery recycling center — never trash

### 7.2 Sharp Edges & Supports

- [ ] Cut supports away from your body, with flush cutters
- [ ] Wear safety glasses when removing resin supports (they ping)
- [ ] Deburr every snap-fit edge that contacts skin (hobby knife, light pass)
- [ ] Wash all skin-contact surfaces in mild soap before first wear

### 7.3 Final Functional Test Gate

Power on. In order:

- [ ] Power LED on the charger module: solid = good
- [ ] MCU power LED: solid = good
- [ ] USB enumerates: new COM/tty device appears
- [ ] `i2c_scan.py` reports `0x5A` and `0x70`
- [ ] First haptic test at intensity 0.2: all 4 LRAs buzz in sequence
- [ ] BLE advertises as `OpenHear-XX:XX` (optional — keep off for first wear)
- [ ] Power draw at idle: <25 mA (multimeter on USB inline meter)

If all 7 boxes are checked → you have a working OpenHear v1.5.

---

## 8. 🎉 You Did It.

You just built an aids-free, sovereign, modular haptic wristband — without a soldering iron, without proprietary firmware, and without sending a byte of audio to anyone's cloud.

### Next Steps

1. **Flash the reference firmware** — see [`firmware_notes.md`](firmware_notes.md). Use the vendor web flasher; keep BLE/cloud off for the first 24 h.
2. **First wear (15 min):** sit in a quiet room. Tap your fingers. Feel the wristband respond. Notice nothing breaks.
3. **Run the audiogram mapper:** calibrate the 24 Bark-band → haptic mapping to your hearing profile. Local-only. Sovereign.
4. **Brain training:** 20 min/day for 14 days. Your cortex will start mapping haptic patterns to phonemes. This is the magic.
5. **Share your build photo** in the OpenHear discussions — color-code, tolerance values, and printer model help the next builder succeed.

Remember: every part is swappable. Every failure is recoverable. Every module is a lego. You are not just a user — you are now a maintainer of your own hearing assistance.

— Built calmly, obsessively, and with love by the OpenHear community.

`[Photo: Final wristband on wrist, LEDs glowing softly, sunset light]`

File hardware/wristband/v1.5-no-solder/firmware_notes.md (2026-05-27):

# Firmware Notes and Connector Pinout: v1.5 No-Solder Modular Edition

v1.5 uses the existing v1 mapping and scheduler concepts with a friendlier connector layout. The firmware goal is unchanged: local Bark-band/audiogram haptic rendering with no cloud dependency.

## Recommended board profiles

### Starter: Seeed XIAO ESP32S3 Sense

- Flashing: USB-C vendor bootloader, Arduino, ESP-IDF, CircuitPython, or MicroPython.
- Best for: compact beginner build with onboard mic for first tests.
- Notes: disable camera features unless explicitly used; keep radio off during latency testing.

### Starter alternate: Adafruit Feather ESP32-S3

- Flashing: USB-C UF2/Arduino/CircuitPython path.
- Best for: larger bay with easy battery ecosystem.
- Notes: FeatherWing/ STEMMA QT ecosystem reduces no-solder wiring risk.

### Research scheduler: RP2040 USB-C board

- Flashing: hold BOOTSEL, plug USB-C, copy UF2.
- Best for: deterministic PIO/DMA timing and dense 64-actuator experiments.
- Notes: add BLE only as a companion/config link, never as the hearing path dependency.

## Connector map

### MCU bay connector `J-MCU-6`

| Pin | Signal | Direction | Notes |
|---:|---|---|---|
| 1 | 3V3 | Out | Logic rail to mux/driver modules only |
| 2 | GND | Common | First-mate/last-break preferred on pogo blocks |
| 3 | SDA | Bidirectional | I2C data to TCA9548A/STEMMA QT |
| 4 | SCL | Out | I2C clock |
| 5 | INT/READY | In | Optional haptic-bank ready/interrupt |
| 6 | EN_HAPTIC | Out | Optional driver-bank enable |

### Battery cartridge connector `J-BAT-4`

| Pin | Signal | Notes |
|---:|---|---|
| 1 | VBAT | Protected LiPo output only |
| 2 | GND | Battery ground |
| 3 | 5V_USB | Charger/dock 5 V when present |
| 4 | BATT_NTC/ID | Optional thermistor or cartridge ID resistor |

### Haptic driver branch `J-HAPTIC-x`

| Pin | Signal | Notes |
|---:|---|---|
| 1 | 3V3 | DRV2605L logic and module power where supported |
| 2 | GND | Shared ground |
| 3 | SDA | Branch-local I2C data from mux |
| 4 | SCL | Branch-local I2C clock from mux |
| 5 | EN | Optional enable |
| 6 | FAULT/READY | Optional status |

### Actuator connector `J-ACT-n`

| Pin | Signal | Notes |
|---:|---|---|
| 1 | ACT+ | Pre-wired LRA lead |
| 2 | ACT- | Pre-wired LRA lead |

Use factory pre-crimped 2-pin JST leads. Do not strip or tin motor wires.

## 24-actuator starter mapping

The 24-actuator build preserves one actuator per Bark-like band.

| Bark band | Actuator | Driver bank | Suggested label |
|---:|---:|---:|---|
| 0 | 0 | 0 | A00 |
| 1 | 1 | 0 | A01 |
| 2 | 2 | 0 | A02 |
| 3 | 3 | 1 | A03 |
| 4 | 4 | 1 | A04 |
| 5 | 5 | 1 | A05 |
| 6 | 6 | 2 | A06 |
| 7 | 7 | 2 | A07 |
| 8 | 8 | 2 | A08 |
| 9 | 9 | 3 | A09 |
| 10 | 10 | 3 | A10 |
| 11 | 11 | 3 | A11 |
| 12 | 12 | 4 | A12 |
| 13 | 13 | 4 | A13 |
| 14 | 14 | 4 | A14 |
| 15 | 15 | 5 | A15 |
| 16 | 16 | 5 | A16 |
| 17 | 17 | 5 | A17 |
| 18 | 18 | 6 | A18 |
| 19 | 19 | 6 | A19 |
| 20 | 20 | 6 | A20 |
| 21 | 21 | 7 | A21 |
| 22 | 22 | 7 | A22 |
| 23 | 23 | 7 | A23 |

## 64-actuator dense mapping

The 64-actuator build uses 4 rings x 16 columns. The existing mapper already supports this with:

```python
WristbandLayout(actuator_count=64)
```

Recommended labels:

- Ring 0 distal/high-elevation row: `R0C00-R0C15`.
- Ring 1: `R1C00-R1C15`.
- Ring 2: `R2C00-R2C15`.
- Ring 3 proximal/low-elevation row: `R3C00-R3C15`.

## Changes needed in existing firmware

No breaking changes are required in `hardware/wristband/firmware/haptic_mapper.py` or `openhear_firmware_v1.py` for the first v1.5 build.

Recommended small adaptation when porting to a real board:

1. Set `DEFAULT_ACTUATOR_COUNT = 24` for starter hardware or pass `actuator_count=64` to `HapticScheduler` for dense hardware.
2. Add a board-specific DRV2605L backend that writes to the selected TCA9548A mux branch before driving a module.
3. Keep `MAX_INTENSITY` conservative for first wear; start with 32/255 and raise only after comfort testing.
4. Keep the existing Bark-band and audiogram weighting logic unchanged so v1.5 remains compatible with v1 training profiles.
5. If using magnetic pogo hot-swap, debounce `EN_HAPTIC` for at least 100 ms after module attach.

## Flashing workflow

1. Install the board vendor's USB driver only if your OS needs it.
2. Plug in USB-C.
3. Enter bootloader mode:
   - XIAO ESP32S3: hold BOOT, tap RESET, release BOOT.
   - Feather ESP32-S3: double-tap RESET for UF2 where supported.
   - RP2040: hold BOOTSEL while plugging USB.
4. Flash your chosen runtime.
5. Copy the adapted `openhear_firmware_v1.py` as the main file.
6. Copy `haptic_mapper.py` or import it from the OpenHear source tree during development.
7. Run an actuator walk test before wearing.

## Local-only sovereignty checklist

- No cloud inference.
- No raw audio upload.
- No account required to hear through haptics.
- BLE/Wi-Fi may be used only for optional companion setup/export.
- Audiogram and haptic preference files stay under user control.

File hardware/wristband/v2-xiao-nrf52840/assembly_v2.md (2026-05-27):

# OpenHear Wristband v2 – Print &amp; Assembly Guide

Licences: hardware **CERN-OHL-S-2.0**, docs **CC-BY-SA-4.0**.

Status: DIY research prototype. **Not a certified hearing aid.** Does not
diagnose, treat, or cure hearing loss. Builders assume prototype risk and
must read [`../assembly_v1.md`](../assembly_v1.md) for the full safety
checklist that still applies in v2.

This guide extends the v1 and v1.5-no-solder philosophy:

- **v1**         = compact, advanced, soldered.
- **v1.5**       = beginner-friendly, no-solder modular, larger.
- **v2 (this)**  = **slim daily-wear**, no-solder by default, looks/feels
  like an Apple Watch Ultra or Whoop 4.0, still 100 % open-source.

## 1. What you’ll print

From `parametric_wristband_v2.scad`, generate two STLs by changing the
`build_part` parameter (or use the pre-oriented STLs in
[`print_pack/stl/`](print_pack/stl/) and the one-page
[`print_pack/PRINT_ME.md`](print_pack/PRINT_ME.md) if you just want to
hand the files to a 3D-print service):

```bash
# from hardware/wristband/v2-xiao-nrf52840/
openscad -D build_part=\"case\" -o case_v2.stl parametric_wristband_v2.scad
openscad -D build_part=\"lid\"  -o lid_v2.stl  parametric_wristband_v2.scad
# Optional integrated TPU stub strap:
openscad -D build_part=\"strap_tpu\" -D strap_style=\"integrated_tpu\" \
         -o strap_stub_v2.stl parametric_wristband_v2.scad
```

### Print settings (FDM, recommended)

| Part | Material | Layer  | Walls | Infill | Supports |
|---|---|---|---|---|---|
| Case | PETG **or** PA12-CF | 0.12 mm| 4 | 30 % gyroid | None (lugs print over short bridge) |
| Lid | PETG matte black | 0.10 mm| 4 | 60 % gyroid | None |
| Strap  | TPU 95A (community) | 0.16 mm| 3 | 100 % concentric | None |

Hard-shell **resin** is also fine if you fully seal the skin side with
medical silicone, exactly as documented in v1.

Print the **case lid in matte black PETG** or PA12-CF for the “titanium
black” daily-wear look. Lightly bead-blast or fine-sand the lid for the
matte finish.

## 2. What you’ll buy

See [`BOM_v2.csv`](./BOM_v2.csv). The recommended no-solder kit:

- **1 ×** Seeed XIAO nRF52840 **Sense** (BLE 5, onboard LiPo charger, PDM mic, IMU)
- **1 ×** Seeed XIAO Expansion Board Base (Grove I²C + JST-PH battery socket)
- **1 ×** Adafruit DRV2605L STEMMA QT haptic driver
- **1 ×** Grove → STEMMA QT/Qwiic cable
- **2 ×** 10 mm pre-wired LRA coin motors (JST-PH lead)
- **1 ×** 3.7 V 300–500 mAh protected LiPo with JST-PH (e.g. **LP502535**)
- **1 ×** 2-pin magnetic pogo pair (one half lives on the case, the other
  becomes your charging dock)
- **1 ×** 20–22 mm quick-release sport band (any CC-licensed community
  parametric Apple-Watch-Ultra-style TPU band from
  **Printables** or **MakerWorld** drops straight in)
- **2 ×** 1.5 mm stainless quick-release spring bars

## 3. Strap options

The case ships with **`strap_style = "lugs"`** by default. That gives you
standard 20 mm or 22 mm quick-release lug pockets so you can use **any**
community-parametric Apple-Watch-style TPU/silicone band as a drop-in
strap. Search Printables / MakerWorld for:

- **“Apple Watch Ultra TPU band parametric”** – many CC-BY-licensed designs.
- **“22 mm quick release strap OpenSCAD”** – fork into the OpenHear repo
  later as a sibling SCAD file.

Set `strap_style = "integrated_tpu"` in the SCAD to print a one-piece TPU
band stub fused to the case (less swappable, but lighter and more
splash-tolerant).

## 4. Assembly steps (no-solder path)

1. **Print** `case_v2.stl` + `lid_v2.stl`. Test-fit the XIAO, LRAs, and
   battery in their pockets. Sand pockets lightly rather than forcing parts.
2. **Click** the XIAO nRF52840 Sense into the Seeed Expansion Board Base.
3. **Plug** the Grove-to-STEMMA QT cable from the expansion board’s I²C
   Grove port into the DRV2605L STEMMA QT input.
4. **Plug** the first LRA into the DRV2605L screw terminal / JST output.
   (For 2 LRAs, daisy-chain a second DRV2605L by changing its I²C address
   – open the ADDR jumper – and adding a second STEMMA QT cable.)
5. **Plug** the LiPo JST-PH lead into the expansion board battery socket.
6. **Flash** the firmware (`firmware/openhear_v2_xiao_nrf52840.ino`)
   over USB-C with the XIAO still outside the case. Confirm it advertises
   as `OpenHear-v2` and that your existing OpenHear phone/companion sees it.
7. **Disconnect** USB-C. Place the XIAO + expansion board into the wrist-side
   pocket, LRAs into their cylinders, battery flat in the lid-side pocket.
8. **Press-fit** the magnetic pogo pair through the two pads on the case
   floor near the lug end; route VBUS to the expansion board USB-C-side
   5 V test pad and GND to a GND pad.
9. **Optional:** line the seal groove on the case rim with a thin strip of
   1 mm self-adhesive silicone foam.
10. **Snap** the lid down. The tongue-and-groove seal lip mates with a
    light press. Add four M1.6 nylon screws only if you plan to sleep or
    swim in the prototype – do **not** swim with a prototype until you
    have completed the IP dry test.
11. **Fit** spring bars + your chosen 20/22 mm strap, and you’re wearing v2.

## 5. Charging dock

The pogo pair gives you an Apple-Watch-style **magnetic snap-on charger**:

- Print or buy a small dock that holds the *other* half of the pogo pair.
- Wire that dock to any standard USB-C 5 V source.
- The XIAO nRF52840 onboard LiPo charger handles termination automatically.
- Never charge unattended during prototyping; protected cells only.

## 6. First-run safety checklist (unchanged from v1)

- Start with `intensity_cap = 32 / 255` and no more than **5 minutes**
  continuous wear.
- Stop for numbness, pain, skin redness, heat, dizziness, or headache.
- Keep user-facing surface below **40 °C**; derate at 38 °C.
- Do **not** sleep with a prototype until battery, charger, and thermal
  tests pass.
- Burgess-Principle binary test: if any raw audio, audiogram data, or
  adaptation data must leave the device/cloud to function, the build
  fails. v2 keeps the same companion-only BLE architecture as v1.

## 7. Compatibility statement

v2 is **wire-compatible** with everything else in the repo:

- Same 3-byte BLE packet `[sound_class_id, intensity, pattern_id]`.
- Same 7-class YAMNet head and same audiogram JSON intensity weighting.
- Same GATT service / characteristic UUIDs as
  `wristband/openhear_firmware.py` and the v1 reference firmware.
- micro:bit v2, ESP32-S3, and RP2040 builds **remain supported as
  legacy options** under `hardware/wristband/` and
  `hardware/wristband/v1.5-no-solder/`. v2 is an additional path, not
  a replacement.

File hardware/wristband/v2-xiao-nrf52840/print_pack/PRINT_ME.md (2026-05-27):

# PRINT ME — OpenHear v2 Wristband

**One page. Hand this to any FDM print service. Print time ≈ 2 h for both parts.**

Licences: hardware **CERN-OHL-S-2.0**, docs **CC-BY-SA-4.0**.
Not a medical device. DIY research prototype.

---

## 1 · Files (already pre-oriented — load and slice)

| File | Part | Footprint (X × Y × Z) | Qty |
|---|---|---|---|
| `stl/openhear_v2_case.stl` | Main case (XIAO + LRA + battery pockets) | 44 × 38 × 9 mm | 1 |
| `stl/openhear_v2_lid.stl`  | Snap-fit lid with tongue seal + logo | 42 × 36 × 2 mm | 1 |

Both STLs rest flat on the build plate at Z = 0. **Do not rotate.**

---

## 2 · Material

| Choice | Recommended | Why |
|---|---|---|
| **Best value (default)** | **PETG, matte black** | Skin-safe, tough, low warp, prints on any FDM machine. |
| Premium daily-wear | PA12-CF (nylon + carbon fibre) | Lighter, stiffer, sweat-proof, matte finish. |
| Hypoallergenic skin | PETG **medical-grade** or PLA + silicone liner | For sensitive skin (always seal the wrist face). |

Avoid raw ABS (warps), and avoid plain PLA for the case (softens with body heat / sun).

---

## 3 · Slicer settings (FDM, 0.4 mm nozzle)

| Setting | Case | Lid |
|---|---|---|
| Layer height | **0.12 mm** | **0.10 mm** |
| Wall / perimeters | **4** | **4** |
| Top / bottom layers | 5 | 5 |
| Infill | **30 % gyroid** | **60 % gyroid** |
| Supports | **None** | **None** |
| Brim | **5 mm** (improves first-layer adhesion on the curved underside) | None |
| Print speed | 40–60 mm/s | 30–40 mm/s (for crisp engraved logo) |
| Bed / nozzle (PETG) | 80 °C / 235 °C | 80 °C / 235 °C |
| Bed / nozzle (PA12-CF) | 90 °C / 280 °C, hardened nozzle | — |

**Estimated material:** ~8 g case + ~3 g lid ≈ **11 g total** per unit.
**Estimated print time:** case ≈ 1 h 30 min, lid ≈ 30 min (Prusa MK4-class).

---

## 4 · Orientation (already baked into the STLs)

```
            ┌──────────────┐   ← curved wrist underside faces UP
   CASE     │   ⌒⌒⌒⌒⌒    │      (open lid-opening rim sits flat on bed)
            └──────────────┘
              ▲ build plate

            ┌──────────────┐   ← engraved “OpenHear” logo faces UP
   LID      │  OpenHear    │      (tongue sealing lip sits flat on bed)
            └──────────────┘
              ▲ build plate
```

Why: the lid-opening rim of the case is the largest flat surface in the
part — putting it on the build plate gives a strong first layer, lets all
internal pockets (XIAO, LRAs, battery) print as straight downward
cavities, and removes any need for supports. The USB-C side cut-out is
small enough to self-bridge.

---

## 5 · Assembly (no tools beyond the parts themselves)

1. Slot the **Seeed XIAO nRF52840 (Sense)** into the labelled pocket; USB-C aligns with the side cut-out.
2. Drop the **2 × 10 mm LRA coin** actuators into their cylindrical pockets (double-sided foam tape OK).
3. (Optional) Slot the **DRV2605L STEMMA QT** into its square pocket and run a Grove cable to the XIAO.
4. Place the **300–500 mAh LiPo (e.g. LP502535)** in the battery bay above the XIAO.
5. Press the **lid** down — the tongue seats into the case groove (snap-fit, no screws).
6. Clip into a standard **20–22 mm quick-release watch strap** at the lugs.

Full electrical wiring, firmware flashing, and the BLE 3-byte packet
contract are in `../assembly_v2.md` and `../firmware/README.md`.

---

## 6 · Recommended print services for 1 unit

| Service | Material | Est. cost (1 unit, case + lid) | Lead time |
|---|---|---|---|
| **JLCPCB 3D printing** | PETG (FDM) | **~US $4–6** + shipping (~$10) | 3–5 days + shipping |
| **Craftcloud / Sculpteo** (price-compare hub) | PETG (FDM) | ~US $8–12 + shipping | 5–7 days |
| **Shapeways** | PA12 (MJF nylon) | ~US $20–25 + shipping | 7–10 days |
| **Local makerspace / Bambu / Prusa owner** | PETG (FDM) | **~US $1–2 in filament** | same day |

**Default recommendation:** PETG on FDM via a local maker or **JLCPCB** —
under US $20 delivered, under 1 week, and a perfect match for the slim
daily-wear case.

---

*Print Me card v1 · OpenHear v2 (XIAO nRF52840) · CC-BY-SA-4.0*

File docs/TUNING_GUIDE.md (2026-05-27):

# OpenHear Tuning Guide

A quick reference for the knobs that matter in
`~/.openhear/config.yaml` and the live `dsp/config.py` defaults.

## Who should read this?

Anyone who has loaded their audiogram, is hearing processed audio in
their aids, and now wants to refine the sound.  The goal is *your*
ears — not a clinic standard.

## The big four

| Knob | What it does | Start here | Symptoms if too high | Symptoms if too low |
|---|---|---|---|---|
| `compression.ratio` | Slope of the WDRC curve. | 2.0–2.5 | Loud consonants sound squashed; music loses punch. | Whispers vanish; loud voices blast. |
| `compression.knee_db` | Level above which compression kicks in (dBFS). | -30 to -35 | Room noise gets amplified. | Quiet speech isn't lifted. |
| `voice.boost_db` | Extra gain in the 1–4 kHz voice band. | +4 to +8 dB | Sibilance, whistling. | Speech sounds muffled or thin. |
| `voice.boost_hz` | Low/high edges of the voice boost band. | `[1000, 4000]` | Too narrow → boomy bass. | Too wide → sharp highs hurt. |

## Quick diagnosis

**"Speech is clear but too sharp at the top."**
  Lower `voice.boost_db` by 2 dB, or pull the high edge of
  `voice.boost_hz` from 4000 down to 3500.

**"Noise gets boosted as much as speech."**
  Reduce `compression.ratio` towards 1.8, or raise
  `compression.knee_db` from -35 towards -28.

**"My own voice booms."**
  Ensure the own-voice bypass is enabled in `dsp/config.py`
  (`OWN_VOICE_BYPASS_ENABLED`) and consider raising the
  `OWN_VOICE_ENERGY_THRESHOLD_DBFS` so it engages more eagerly.

**"Whistling / feedback."**
  Drop `ANTI_FEEDBACK_GAIN_DB` by 2 dB at a time.  If it persists, run
  `python -m dsp.pipeline --test-tone` and watch the
  `dsp.feedback_canceller` log output.

## Measuring before you change

Before adjusting anything, capture a baseline:

```
python -m stream.recorder --raw raw.wav --processed proc.wav --duration 30
python -m stream.latency  --target 20
python -m dsp.pipeline     --metrics-csv metrics.csv &
```

Keep the WAVs and the CSV — if a later change sounds worse, A/B them
against the baseline.

## Offline evaluation

Use `examples/demo.py` to run a candidate config against a known WAV
file without any real-time pressure:

```
python examples/demo.py -i speech.wav -o processed.wav \
        --config my-candidate.yaml
```

Compare `speech.wav` and `processed.wav` in any DAW or in Audacity.

## Staying safe

* Keep `dsp/config.py` read-only after your first tuning session — put
  all personal overrides in `~/.openhear/config.yaml` instead.
* Before writing any fitting change back to the aids, confirm
  `core.backup.write_backup` has written a recent archive under
  `output/backups/` (`core.write_fitting.write_safe_parameters` does
  this automatically — check the log line it emits).
* If any new setting makes things sound drastically different, revert
  with `python -m core.read_fitting --session -o last.json` and
  compare.

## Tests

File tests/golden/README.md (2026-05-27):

# Golden DSP vectors

These files are the **frozen reference** for OpenHear's DSP stages.
They are generated by `python -m scripts.benchmark --regen-golden`
and consumed by `tests/test_golden_vectors.py` and the benchmark
harness's parity check.

If a code change in `dsp/` causes any of these vectors to diverge,
that is **by definition** an algorithmic change and must be
accompanied by an explicit regeneration commit and a CHANGELOG
entry.  Do not regenerate silently.

Files:

* `input.npy` — deterministic float32 input frames (seed 0xdeadbeef).
* `noise_reduction.npy` — `SpectralSubtractor` output.
* `compression.npy` — `WDRCompressor` output.
* `voice_clarity.npy` — `VoiceClarityEnhancer` output.
* `feedback.npy` — `FeedbackCanceller` output.

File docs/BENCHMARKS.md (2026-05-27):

# OpenHear — DSP Benchmark Methodology

> **Status.** v1, May 2026. Foundational artefact for Workstream A of
> the Phase 1 90-Day Master Plan.
>
> **Why this document exists.** Every quantitative claim OpenHear
> makes about latency, throughput or real-time headroom must be
> reproducible by an independent third party from a clean checkout
> with one command. This page specifies how.

## 1. Run it

```bash
make install-dev      # one-off
make benchmark        # prints a signed JSON report on stdout
```

Or, equivalently:

```bash
python -m scripts.benchmark --frames 1000 --out benchmark_report.json
```

The harness needs no microphone, no speaker, no Bluetooth, and no
audiogram. It can be run on a developer laptop, a Raspberry Pi 5, a
CI runner or a clean-room lab machine — the resulting numbers are
directly comparable because the input signal, the DSP code and the
algorithm parameters are all pinned.

## 2. What it measures

For each of the four core Python DSP stages —
[`SpectralSubtractor`](../dsp/noise_reduction.py),
[`WDRCompressor`](../dsp/compression.py),
[`VoiceClarityEnhancer`](../dsp/voice_clarity.py),
[`FeedbackCanceller`](../dsp/feedback_canceller.py) — and for the full
chain stitched together in pipeline order, the harness reports:

| Field | Meaning |
|---|---|
| `frames` | Number of frames timed (after warm-up). |
| `frame_duration_ms` | Real-time audio duration of one frame at the configured sample rate. |
| `p50_ms` / `p95_ms` / `p99_ms` / `max_ms` | Wall-clock processing time percentiles per frame. |
| `mean_ms` | Mean processing time per frame. |
| `realtime_factor_p95`  | `frame_duration_ms / p95_ms`. Values > 1 indicate the stage is real-time at the 95th percentile; values < 1 indicate it is *not* real-time. |

The first 10 % of frames are discarded as warm-up so that interpreter
JIT, BLAS first-call costs and cache effects do not dominate the
percentiles.

## 3. Why the numbers can be trusted

1. **Deterministic input.** The audio buffer is generated from a
   fixed seed (`0xCAFEBABE`) as a mixture of low-amplitude white
   noise plus 440 Hz and 2 kHz sinusoids. The same buffer is fed to
   every stage on every run.
2. **Bit-parity guard.** Before timing, the harness re-runs every
   stage on a separate fixed golden frame (`tests/golden/`) and
   refuses to emit a report unless the output matches the committed
   reference within ~1 LSB at single precision. This means a
   benchmark report is, by construction, a benchmark of an
   *unchanged* algorithm. CI enforces the same parity check via
   [`tests/test_golden_vectors.py`](../tests/test_golden_vectors.py).
3. **Self-signed report.** The JSON report contains a
   `report_sha256` field whose value is the SHA-256 of the report
   body with that field nulled out. A reader can recompute and
   verify it independently — no external trust required, in keeping
   with the [Burgess Principle](BURGESS_PRINCIPLE.md).
4. **Provenance fields.** Every report carries `git_sha`, host
   platform, machine type, Python version and numpy version so that
   apparent regressions can be diagnosed without extra metadata.

## 4. Interpreting a report

A typical developer-laptop run on the current Python pipeline
(numbers will differ on your hardware; this is illustrative, **not** a
performance claim):

```
config: { "sample_rate": 16000, "frames_per_buffer": 256 }
=> frame_duration_ms = 16.0

stages:
  noise_reduction.p95_ms ≈ 0.04  (realtime_factor ≈ 400×)
  voice_clarity.p95_ms   ≈ 0.02  (realtime_factor ≈ 800×)
  compression.p95_ms     ≈ 0.50  (realtime_factor ≈ 30×)
  feedback.p95_ms        ≈ 3.20  (realtime_factor ≈ 5×)
  full_pipeline.p95_ms   ≈ 3.85  (realtime_factor ≈ 4×)
```

Key reading guidance:

* `full_pipeline.p95_ms` is the only number that should be quoted in
  external communications. Single-stage numbers are diagnostic, not
  promotional.
* `realtime_factor_p95 > ~3` is the working threshold for "real-time
  capable on this CPU". Below ~1.5, the pipeline is at risk of
  buffer underrun under load.
* The benchmark measures **DSP cost only**. Real end-to-end
  microphone-to-output latency adds the audio I/O round-trip, which
  is platform-specific and tracked separately by
  [`stream/latency.py`](../stream/latency.py) once a real device is
  attached.

## 5. Honest limitations (read this before quoting numbers)

The current harness measures what it can measure honestly. The
following are **explicit gaps** that Workstream A will close in
days 31–90 and beyond; until then, do not paper over them.

* **No audio I/O included.** Microphone capture, output buffering and
  Bluetooth transport latency are not measured here. Sub-5 ms claims
  cannot be made from this report alone.
* **No power measurement.** Wall-clock time is not energy. A separate
  campaign on a USB power meter is required for the
  `<50 mW` Phase 3 target.
* **CPython, not the future native core.** The Phase 1 plan calls for
  a C++/Rust port (Day 31–60). When that lands, the same harness
  will time both implementations and emit them as parallel sections,
  so absolute numbers can be compared like-for-like.
* **No Raspberry Pi 5 numbers committed yet.** The repository does
  not yet include a benchmark report from a Pi 5. The harness will
  produce one as soon as a unit is on a contributor's bench;
  contributions of `benchmark_report.json` files for diverse hosts
  are explicitly invited (see §7).

## 6. Regenerating golden vectors (rare, deliberate)

Golden vectors freeze the *current* DSP behaviour. You only
regenerate them after an intentional algorithmic change — for
example, a bug fix, a new compression algorithm, or an upstream
numpy change that legitimately alters numerical output.

```bash
python -m scripts.benchmark --regen-golden
git diff tests/golden/   # review the diff carefully
git add tests/golden/
# add a CHANGELOG entry explaining *why* the algorithm changed.
```

If the parity check ever fails unexpectedly in CI, that is the
desired behaviour: a silent change to a DSP coefficient is exactly
what this guard exists to catch.

## 7. Contributing a report

Run the benchmark on your hardware and open a PR adding the JSON to
`docs/benchmarks/<short-host-id>.json`. We particularly want runs
from:

* Raspberry Pi 5 (4 GB and 8 GB).
* Jetson Orin Nano.
* Apple Silicon (M1/M2/M3).
* Older x86 laptops, to bound the lower end.

A directory full of these reports is the cheapest credible answer to
the question "does OpenHear actually run in real time?" — and it is
the kind of artefact a grant reviewer or journal editor can verify in
60 seconds.

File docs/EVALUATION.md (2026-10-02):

# Evaluation — awareness, not hearing restoration

This page is for a funder or a clinic. A first-time user does not need it. Start at [START_HERE.md](../START_HERE.md).

Health Innovation NENC (September 2026) said the remaining job is evidence that this implementation delivers meaningful benefit in real use. This is the smallest study that answers that, without claiming treatment.

## What is being measured

Whether a wearer can tell which class of sound happened, from a wrist pattern, in ordinary rooms.

Classes only:

- voice present (not what was said)
- doorbell or chime
- alarm or siren
- animal
- traffic or vehicle warning
- television, radio, or other media
- silence / no significant event

## What is not being measured

- Speech understanding.
- Aided thresholds.
- Tinnitus change.
- Replacement of a hearing aid or a cochlear implant.

## Record, per session

- Event class the system reported.
- Event class the wearer named from the pattern.
- Missed events the wearer later confirmed.
- False alerts.
- Whether the pattern was learnable after a short familiarisation, and after a week.

A result is a count of hits, misses, and false alerts. It is not a clinical claim.

OpenHear remains an environmental sound awareness tool. It is not a medical device.

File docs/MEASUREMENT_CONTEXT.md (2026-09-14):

# Measurement context

A Living Hearing Profile must not treat a single audiogram as the person.

## Rule

When a threshold graph is ingested, record *how the test was taken* as a first-class field, not a footnote.

In scope:

- Severe tinnitus on the test day
- Fatigue or illness at the session
- First test versus a known previous graph that has moved
- Aids in or out during the booth test, if known
- Speech-banana overlay: which phonemes sit above the measured line

Out of scope in the public tree: names, clinic identifiers, device serials, appointment diaries, dates of birth.

## Why it belongs

A graph taken in a bad tinnitus week can look like progression. Without the context field, the next clinician, or the DSP, will treat the worse numbers as the new baseline. The profile should say: these thresholds were measured under X. Recheck when X is quieter.

The speech-banana overlay is the same idea applied to *what the person cannot collect*. Vowels and low consonants can remain on the page while s, f and th sit above the line. A general lip-reading class then feels like failure. The profile should name the missing set so practice can target those shapes, including with a familiar face rather than a long course.

This is user-declared. It is not inferred from the image by a clinic cloud.

## Anonymised shapes added from consented panel correspondence

**Flat-ish moderate-to-severe through the speech frequencies, with a further drop at 8 kHz.** Distinct from a steep industrial slope (preserved lows, cliff after 500–750 Hz). DSP implication: broadband lift rather than a high-frequency-only shelf; watch residual dynamic range; do not discard a prior graph because one noisy-tinnitus session moved the points.

**Sloping moderate-to-severe, high-frequency drop, speech-banana consonants above the line.** Adult long-term aid user. Approximate PTA mid-50s to mid-60s; right a little worse than left at 4–8 kHz. Distinct from the flat-ish shape above and from the industrial cliff. DSP implication: preserve low-to-mid speech; do not treat residual vowel hearing as proof that s / f / th are available; haptic or visual second channel still earns its place when aids are out. No name, date of birth or clinic header in this tree.

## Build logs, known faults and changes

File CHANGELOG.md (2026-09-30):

# Changelog

All notable changes to OpenHear will be documented in this file.

The format is based on [Keep a Changelog](https://keepachangelog.com/en/1.1.0/),
and this project adheres to [Semantic Versioning](https://semver.org/spec/v2.0.0.html)
once it reaches `1.0.0`. Until then, breaking changes may land in any `0.x`
release; they will be called out under a **Breaking** subsection.

## [Unreleased]

### Added

- **Bone-conduction output pathway** (`dsp/bone_conduction.py`, `docs/BONE_CONDUCTION_PATHWAY.md`) — audiogram-driven gain retargeted for a contact transducer (mastoid / forehead / abutment / unspecified). Uses BC thresholds when supplied, otherwise AC. Generic compensation table is OpenHear's, not a copied manufacturer curve. SSD contralateral routing is a label. Oral / tooth is not a coupler value.
- **Sonitus / SoundBite FTO working note** (`docs/FTO_SONITUS.md`) and unpublished hold at `modules/optional/oral_appliance/`. Live Shanghai / EP / US claims and the SOUNDBITE mark stay off the public drawings. Not legal advice; attorney review required before any intra-oral file.
- **Speech-banana as measurement context** (`docs/MEASUREMENT_CONTEXT.md`) — which phonemes sit above the measured line is a first-class field. New consented, de-identified archetype: sloping moderate-to-severe with high-frequency consonants (s, f, th) above the line. No name, date of birth or clinic header in the public tree.
- **Measurement context** — tinnitus, fatigue or illness on the test day is a first-class Living Profile field, so one worse booth session is not treated as the new person. Includes an anonymised flat-ish moderate-to-severe / 8 kHz-drop shape.
- **Systemic Context Layer with hard sensory-modulation boundary** (`docs/SYSTEMIC_CONTEXT_LAYER.md`) — optional sixth surface of `openhear-living-profile-v1`. A factor is included only if it directly modulates sensory experience or access to sensory healthcare. In: fatigue, housebound status, transport barriers, ototoxic / auditory-processing medications. Out: renal/metabolic/inflammatory labs as such; housing, finances, energy, and legal matters unless they create a direct sensory-access barrier. User-declared, never inferred. No identifiable results in the public tree.
- **Aids-out night safety and rear-approach awareness** (`docs/AIDS_OUT_AND_REAR_APPROACH.md`).
- **Auracast design relationship** (`docs/AURACAST.md`).
- **Hearing loss and dementia — clinical context** (`docs/HEARING_LOSS_AND_DEMENTIA.md`).
- **Living Hearing Profile v8–v9** and consented anonymised audiogram examples.

## [1.5.0] - 2026-08-16

### Added

- Living Hearing Profile advancement, consented profound-asymmetric audiogram example, live wristband accessibility profiles, Residual Witness protocol (draft).

## [1.4.0] - 2026-07-08

### Added

- Output-safety limiter, fatigue-aware DSP hooks, per-contact profile bank, Superior Hearing roadmap.

## [1.3.0] - 2026-06-02

### Added

- Therapeutic frequency delivery (Pillar 5).

## [1.2.0] - 2026-06-02

### Added

- Plain-English audiogram interpretation; shared haptic-packet codec.

## [1.1.0]

### Added

- Burgess Principle reference layer, Apache 2.0 + Sovereign Use Addendum, wristband stack, north-star documents.

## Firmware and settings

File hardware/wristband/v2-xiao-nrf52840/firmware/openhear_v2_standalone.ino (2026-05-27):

// OpenHear Wristband v2 — Standalone (No Phone) Firmware  rev 2
// Target:   Seeed Studio XIAO nRF52840 Sense
// Licence:  MIT OR Apache-2.0
//
// WHAT'S NEW vs rev 1
// -------------------
// 1. Dual DRV2605L haptic drivers — left motor (0x5A) and right motor (0x5B)
//    fire independently.  Each sound class now has a spatial encoding that
//    tells you more than just "something happened" — voice and alarm use
//    both motors, vehicle uses the left (UK road side), dog uses right, etc.
//    Ported directly from stream/haptic_mapper.py in the OpenHear repo.
//
// 2. IMU seek mode — the XIAO nRF52840 Sense has an onboard LSM6DS3
//    accelerometer/gyroscope.  When seek mode is active, the firmware tracks
//    your rotation and listens for amplitude increase as you face a sound
//    source.  When the correlation peaks, a "found it" double-tap fires on
//    both motors.  This gives directional feedback without needing a second
//    microphone.  Activate by raising then lowering the wrist sharply once.
//
// 3. Ten sound classes instead of six.  Add dog_bark, phone_ring, and
//    music_tv to your Edge Impulse project (see STANDALONE.md for the
//    updated class list and free sample sources).
//
// 4. Extended band indicators.  Sub-bass heavy sounds (vehicles, construction)
//    use a long slow pulse on the left motor.  High-frequency alerts (alarms,
//    appliances) use rapid right-biased patterns.  This encodes frequency
//    range as haptic texture so you gain a rough sense of pitch on the wrist.
//
// BEFORE COMPILING
// ----------------
// 1. Train your Edge Impulse model with the 10 classes listed below.
//    See STANDALONE.md for the updated class list and free sample sources.
// 2. Export as an Arduino library and install it.
// 3. Change the #include below to match your exported library name.
// 4. Library Manager — install (in addition to previous requirements):
//    - Seeed_Arduino_LSM6DS3   (for the onboard IMU)
// 5. If you only have ONE DRV2605L, set DUAL_MOTOR false below — the firmware
//    falls back gracefully to single-motor mode.
// 6. Upload.  Two taps = ready.

#include <Arduino.h>
#include <Wire.h>
#include <PDM.h>
#include <Adafruit_DRV2605.h>
#include <LSM6DS3.h>   // Seeed_Arduino_LSM6DS3

// Replace with your Edge Impulse exported library name:
#include "openhear-classifier_inferencing.h"

// ============================================================================
// BUILD OPTIONS
// ============================================================================
#define DUAL_MOTOR       true   // set false if you only fitted one DRV2605L
#define SEEK_MODE_ENABLE true   // set false to disable IMU direction mode

// ============================================================================
// SOUND CLASSES
// These must match the label order in your Edge Impulse project exactly.
// Train Edge Impulse with these 10 labels in this order:
//
//  0  voice       — speech, conversation
//  1  alarm       — fire alarm, smoke detector, siren, alarm clock
//  2  doorbell    — door chime, ding-dong
//  3  baby_cry    — infant crying
//  4  vehicle     — car, engine, traffic, motorcycle
//  5  appliance   — kettle, microwave, beep
//  6  dog_bark    — dog, bark, howl             (NEW)
//  7  phone_ring  — phone ringing, ringtone     (NEW)
//  8  music_tv    — music, television, radio    (NEW)
//  9  ambient     — background noise, silence   (was class 6)
//
// ============================================================================
static const uint8_t CLASS_VOICE      = 0;
static const uint8_t CLASS_ALARM      = 1;
static const uint8_t CLASS_DOORBELL   = 2;
static const uint8_t CLASS_BABY_CRY   = 3;
static const uint8_t CLASS_VEHICLE    = 4;
static const uint8_t CLASS_APPLIANCE  = 5;
static const uint8_t CLASS_DOG        = 6;
static const uint8_t CLASS_PHONE      = 7;
static const uint8_t CLASS_MUSIC_TV   = 8;
static const uint8_t CLASS_AMBIENT    = 9;

// ============================================================================
// AUDIOGRAM INTENSITY TABLE
// Derived from burgess_2021.json — baked in so no phone or JSON file needed.
// Formula: intensity = (avg_loss_dB / 100) * 180, clamped 0–180.
// To recalculate for a different person see STANDALONE.md.
// ============================================================================
static const uint8_t AUDIOGRAM_INTENSITY[10] = {
    128,   // 0 voice      — loss ~71 dB avg (500–2000 Hz)
    147,   // 1 alarm      — loss ~82 dB avg (2000–4000 Hz)
    140,   // 2 doorbell   — loss ~78 dB avg (800–2000 Hz)
    135,   // 3 baby_cry   — loss ~75 dB avg (500–4000 Hz)
     68,   // 4 vehicle    — loss ~38 dB avg (100–500 Hz)  ← partly audible
    140,   // 5 appliance  — loss ~78 dB avg (1000–3000 Hz)
     90,   // 6 dog_bark   — loss ~50 dB avg (500–1000 Hz)
    128,   // 7 phone_ring — loss ~71 dB avg (1000–2000 Hz)
    110,   // 8 music_tv   — loss ~61 dB avg (500–2000 Hz)
    100,   // 9 ambient    — broadband, low priority
};

// ============================================================================
// SPATIAL HAPTIC ENCODING
// Ported from stream/haptic_mapper.py in the OpenHear repo.
// Each sound class specifies which motor(s) fire and in what sequence.
//
// Motor conventions (worn on left wrist, viewed from above):
//   LEFT  motor (DRV2605L at I2C 0x5A, default) = closer to thumb
//   RIGHT motor (DRV2605L at I2C 0x5B, ADDR pin HIGH) = closer to little finger
//
// Spatial vocabulary:
//   BOTH  — omnidirectional / urgent
//   LEFT  — sound typically from left (vehicle in UK = road is left)
//   RIGHT — sound from right / personalised attention side
//   ALT   — alternating L/R = source direction unknown, use seek mode
// ============================================================================
static const uint8_t MOTOR_BOTH  = 0;
static const uint8_t MOTOR_LEFT  = 1;
static const uint8_t MOTOR_RIGHT = 2;
static const uint8_t MOTOR_ALT   = 3;

struct HapticPattern {
    uint8_t  routing;       // MOTOR_BOTH / LEFT / RIGHT / ALT
    uint8_t  effect_left;   // DRV2605 ROM effect ID for left motor
    uint8_t  effect_right;  // DRV2605 ROM effect ID for right motor
    uint8_t  repeats;       // times to fire
    uint16_t gap_ms;        // ms between repeats
};

static const HapticPattern HAPTIC[10] = {
    // voice      — both motors, gentle sustained buzz
    {MOTOR_BOTH,  14, 14, 1,   0},
    // alarm      — alternating L/R urgent × 3 (use seek mode to find source)
    {MOTOR_ALT,   47, 47, 3, 150},
    // doorbell   — both motors, sharp double knock
    {MOTOR_BOTH,  24, 24, 2, 100},
    // baby_cry   — right motor rising ramp (personalised attention side)
    {MOTOR_RIGHT,  1, 82, 1,   0},
    // vehicle    — left motor single long pulse (UK: road traffic from left)
    {MOTOR_LEFT,  48,  1, 1,   0},
    // appliance  — both motors short double-click (beep-like)
    {MOTOR_BOTH,  26, 26, 1,   0},
    // dog_bark   — right motor single medium pulse
    {MOTOR_RIGHT,  1, 48, 1,   0},
    // phone_ring — both motors alternating × 2 (ring cadence)
    {MOTOR_ALT,   14, 14, 2, 400},
    // music_tv   — both motors slow soft pulse × 2
    {MOTOR_BOTH,  58, 58, 2, 500},
    // ambient    — never fired (filtered before play_haptic)
    {MOTOR_BOTH,   0,  0, 0,   0},
};

// ============================================================================
// SETTINGS
// ============================================================================
static const float    CONFIDENCE_THRESHOLD = 0.75f;
static const uint32_t MIN_GAP_MS           = 1500;
static const uint32_t SEEK_WINDOW_MS       = 5000;   // seek mode timeout (ms)
static const float    SEEK_GAIN_THRESHOLD  = 1.15f;  // 15% amplitude rise = found it
static const float    WRIST_FLICK_G        = 2.2f;   // G-force to trigger seek

// ============================================================================
// GLOBALS
// ============================================================================
Adafruit_DRV2605 drv_left;    // 0x5A
Adafruit_DRV2605 drv_right;   // 0x5B
LSM6DS3          imu(I2C_MODE, 0x6A);

static int16_t   inference_buffer[EI_CLASSIFIER_DSP_INPUT_FRAME_SIZE];
static bool      buffer_ready   = false;
static uint32_t  last_haptic_ms = 0;

static bool      seek_active    = false;
static uint32_t  seek_start_ms  = 0;
static float     seek_baseline  = 0.0f;
static float     seek_peak      = 0.0f;

// PDM interrupt callback
void onPDMdata() {
    int bytes = PDM.available();
    PDM.read(inference_buffer, bytes);
    buffer_ready = true;
}

// ============================================================================
// MOTOR HELPERS
// ============================================================================
bool right_motor_present() {
#if !DUAL_MOTOR
    return false;
#else
    Wire.beginTransmission(0x5B);
    return (Wire.endTransmission() == 0);
#endif
}

void init_drv(Adafruit_DRV2605 &drv) {
    drv.begin();
    drv.setMode(DRV2605_MODE_INTTRIG);
    drv.useLRA();        // LRA coin motors — better frequency response than ERM
    drv.selectLibrary(6);  // library 6 = LRA; change to 1 if using ERM motors
}

void fire_effect(Adafruit_DRV2605 &drv, uint8_t effect, uint8_t intensity) {
    drv.writeRegister8(0x17, intensity);
    drv.setWaveform(0, effect);
    drv.setWaveform(1, 0);
    drv.go();
}

void stop_all() {
    drv_left.stop();
    drv_right.stop();
}

// ============================================================================
// SETUP
// ============================================================================
void setup() {
    Wire.begin();

    init_drv(drv_left);
    init_drv(drv_right);   // harmless if right motor absent

#if SEEK_MODE_ENABLE
    imu.begin();
#endif

    // Startup confirmation: two short taps
    fire_effect(drv_left, 26, 120);
    delay(300);
    fire_effect(drv_left, 26, 120);
    delay(300);
    stop_all();

    PDM.onReceive(onPDMdata);
    PDM.begin(1, EI_CLASSIFIER_FREQUENCY);
}

// ============================================================================
// PLAY HAPTIC
// Applies spatial routing and audiogram-scaled intensity.
// ============================================================================
void play_haptic(uint8_t class_id) {
    const HapticPattern &p = HAPTIC[class_id];
    uint8_t intensity      = AUDIOGRAM_INTENSITY[class_id];
    bool    right_ok       = right_motor_present();

    for (uint8_t r = 0; r < p.repeats; r++) {
        if (p.gap_ms > 0 && r > 0) delay(p.gap_ms);

        switch (p.routing) {

            case MOTOR_BOTH:
                fire_effect(drv_left,  p.effect_left,  intensity);
                if (right_ok) fire_effect(drv_right, p.effect_right, intensity);
                break;

            case MOTOR_LEFT:
                fire_effect(drv_left, p.effect_left, intensity);
                if (right_ok) drv_right.stop();
                break;

            case MOTOR_RIGHT:
                if (right_ok) {
                    fire_effect(drv_right, p.effect_right, intensity);
                    drv_left.stop();
                } else {
                    fire_effect(drv_left, p.effect_left, intensity);  // fallback
                }
                break;

            case MOTOR_ALT:
                // Odd pulse = left, even pulse = right
                if (r % 2 == 0) {
                    fire_effect(drv_left, p.effect_left, intensity);
                    if (right_ok) drv_right.stop();
                } else {
                    if (right_ok) {
                        fire_effect(drv_right, p.effect_right, intensity);
                        drv_left.stop();
                    } else {
                        fire_effect(drv_left, p.effect_left, intensity);
                    }
                }
                break;
        }
        delay(80);
    }

    stop_all();
    last_haptic_ms = millis();
}

// ============================================================================
// SEEK MODE
//
// How it works:
//   1. A sharp wrist flick (IMU > WRIST_FLICK_G) activates seek mode.
//      A short single buzz confirms it's on.
//   2. For up to SEEK_WINDOW_MS the firmware tracks PDM amplitude.
//   3. As you rotate your body toward the sound source, the mic picks up
//      marginally more signal (body-shadow effect on an omnidirectional mic).
//   4. When amplitude climbs > SEEK_GAIN_THRESHOLD × baseline, a double-tap
//      fires on both motors: you're facing the source.
//   5. Mode exits.  If you don't find the source in time, it exits silently.
//
// This gives directional awareness with zero extra hardware.
// ============================================================================
#if SEEK_MODE_ENABLE

float rms_of_buffer() {
    int n = min((int)EI_CLASSIFIER_DSP_INPUT_FRAME_SIZE, 512);
    float sum = 0.0f;
    for (int i = 0; i < n; i++) {
        float s = inference_buffer[i] / 32768.0f;
        sum += s * s;
    }
    return sqrtf(sum / n);
}

void check_seek_trigger() {
    float ax = imu.readFloatAccelX();
    float ay = imu.readFloatAccelY();
    float az = imu.readFloatAccelZ();
    float g  = sqrtf(ax*ax + ay*ay + az*az);

    if (g > WRIST_FLICK_G && !seek_active) {
        seek_active   = true;
        seek_start_ms = millis();
        seek_baseline = rms_of_buffer() + 1e-6f;
        seek_peak     = seek_baseline;
        fire_effect(drv_left, 14, 80);
        delay(60);
        stop_all();
    }
}

void update_seek() {
    if (!seek_active) return;

    if ((millis() - seek_start_ms) > SEEK_WINDOW_MS) {
        seek_active = false;
        return;
    }

    float level = rms_of_buffer();
    if (level > seek_peak) seek_peak = level;

    if (seek_peak >= seek_baseline * SEEK_GAIN_THRESHOLD) {
        // Found it
        bool right_ok = right_motor_present();
        for (uint8_t i = 0; i < 2; i++) {
            fire_effect(drv_left, 24, 160);
            if (right_ok) fire_effect(drv_right, 24, 160);
            delay(120);
            stop_all();
            delay(80);
        }
        seek_active = false;
    }
}

#endif  // SEEK_MODE_ENABLE

// ============================================================================
// MAIN LOOP
// ============================================================================
void loop() {
#if SEEK_MODE_ENABLE
    check_seek_trigger();
    update_seek();
#endif

    if (!buffer_ready) return;
    buffer_ready = false;

    signal_t signal;
    int err = numpy::signal_from_buffer(
        inference_buffer,
        EI_CLASSIFIER_DSP_INPUT_FRAME_SIZE,
        &signal
    );
    if (err != 0) return;

    ei_impulse_result_t result = { 0 };
    err = run_classifier(&signal, &result, false);
    if (err != EI_IMPULSE_OK) return;

    uint8_t best_class = 0;
    float   best_score = 0.0f;
    for (uint8_t i = 0; i < EI_CLASSIFIER_LABEL_COUNT; i++) {
        if (result.classification[i].value > best_score) {
            best_score = result.classification[i].value;
            best_class = i;
        }
    }

    bool confident   = best_score >= CONFIDENCE_THRESHOLD;
    bool gap_ok      = (millis() - last_haptic_ms) >= MIN_GAP_MS;
    bool not_ambient = (best_class != CLASS_AMBIENT);

    if (confident && gap_ok && not_ambient) {
        play_haptic(best_class);
    }

    delay(10);
}

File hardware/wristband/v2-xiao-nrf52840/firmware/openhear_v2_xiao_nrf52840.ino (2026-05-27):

// OpenHear Wristband v2 - "Premium Slim" firmware
// Target board:  Seeed Studio XIAO nRF52840 (or XIAO nRF52840 Sense)
// Toolchain:     Arduino IDE + Seeed nRF52 mbed-enabled BSP
// Radio stack:   NimBLE-Arduino (preferred) OR Adafruit Bluefruit nRF52 BLE
// Haptic stack:  Adafruit DRV2605 Library (open-source, MIT)
//
// Licence: MIT OR Apache-2.0 (matches v1 firmware)
//
// CONTRACT WITH THE REST OF THE OPENHEAR STACK (DO NOT CHANGE):
//   - Same 3-byte BLE haptic packet  [sound_class_id, intensity, pattern_id]
//   - Same 7 YAMNet sound classes (IDs 0..6) + audiogram JSON intensity weighting
//   - BLE is companion-only; on-wrist haptics MUST never depend on the radio
//   - Local-first, Burgess-Principle: no raw audio leaves the device
//
// This sketch keeps the high-level architecture identical to
//   wristband/openhear_firmware.py and hardware/wristband/firmware/openhear_firmware_v1.py
// so the existing classifier, audiogram, and phone tools stream into it unchanged.
//
// Pin map (default XIAO nRF52840 Sense, no-solder via Seeed Expansion Base):
//   D4 / D5  -> I2C SDA / SCL  (DRV2605L + optional TCA9548A)
//   D0       -> optional GPIO IRQ from a future second DRV2605L bank
//   onboard  -> PDM mic (Sense only), IMU LSM6DS3TR-C (Sense only)
//   VBUS     -> USB-C 5 V (also routed to magnetic pogo dock pads)
//
// Sleep strategy: System OFF between BLE events; DRV2605L is put in standby
// after every effect; LED is never driven in production builds.

#include <Arduino.h>
#include <Wire.h>
#include <Adafruit_DRV2605.h>

// ---- BLE backend selection -------------------------------------------------
// Define exactly one of these before the include.
#define OPENHEAR_USE_NIMBLE 1
// #define OPENHEAR_USE_BLUEFRUIT 1

#if defined(OPENHEAR_USE_NIMBLE)
  #include <NimBLEDevice.h>
#elif defined(OPENHEAR_USE_BLUEFRUIT)
  #include <bluefruit.h>
#else
  #error "Define OPENHEAR_USE_NIMBLE or OPENHEAR_USE_BLUEFRUIT"
#endif

// ============================================================================
// Constants - must match the rest of OpenHear
// ============================================================================
static const char*   DEVICE_NAME            = "OpenHear-v2";
static const uint8_t MAX_INTENSITY          = 180;   // matches v1 cap
static const uint8_t NUM_SOUND_CLASSES      = 7;     // YAMNet 7-class head
static const uint8_t V0_COMPAT_PATTERN      = 240;   // matches v1 firmware
static const uint32_t IDLE_SLEEP_AFTER_MS   = 8000;  // enter low-power after silence

// OpenHear haptic service - keep these UUIDs stable across firmware versions.
// They are the same UUIDs published by the v1 Python firmware reference.
#define OPENHEAR_SVC_UUID    "6f68656172-0000-1000-8000-00805f9b34fb"
#define OPENHEAR_PKT_CHR_UUID "6f68656172-0001-1000-8000-00805f9b34fb"  // write: 3-byte packet
#define OPENHEAR_CFG_CHR_UUID "6f68656172-0002-1000-8000-00805f9b34fb"  // write: [actuator_count, intensity_cap]

// ============================================================================
// Haptic effect map - one open-source DRV2605 ROM effect per sound class.
// Index = sound_class_id (0..6). Tune to your audiogram JSON.
//
// Class IDs MUST match the YAMNet 7-class head defined in
// yamnet_classifier.py / audiogram/*.json so the phone and the wrist agree.
// ============================================================================
struct ClassEffect {
    const char* label;           // human label, for debug only
    uint8_t     primary_effect;  // DRV2605 ROM library effect 1..123
    uint8_t     accent_effect;   // optional second effect played on a 2nd LRA
    uint8_t     repeat;          // number of times to play primary
    uint8_t     min_intensity;   // floor (avoid sub-threshold buzz)
};

static const ClassEffect CLASS_EFFECTS[NUM_SOUND_CLASSES] = {
    // id 0: speech            - soft, sustained
    { "speech",          14, 17, 1,  40 },  // "Strong buzz 60%" + "Strong click 60%"
    // id 1: alarm/siren       - sharp, urgent, repeated
    { "alarm",           47,  1, 3,  80 },  // "Buzz 1 - 100%" x3
    // id 2: doorbell/knock    - double-click feel
    { "doorbell",        24, 27, 2,  60 },  // "Sharp click 100%" + "Short double click strong"
    // id 3: baby cry          - long ramp
    { "baby_cry",        82, 70, 2,  70 },  // "Transition ramp up long sharp"
    // id 4: vehicle/horn      - hard pulse
    { "vehicle",         48,  3, 2,  90 },  // "Buzz 2 - 80%"
    // id 5: appliance beep    - triple short tick
    { "appliance",       26, 27, 3,  40 },  // "Short double click medium"
    // id 6: ambient/other     - gentle awareness pulse
    { "ambient",         58,  0, 1,  30 },  // "Long buzz no stop"
};

// ============================================================================
// Globals
// ============================================================================
Adafruit_DRV2605 g_drv;
volatile bool    g_drv_present     = false;
volatile uint8_t g_intensity_cap   = MAX_INTENSITY;
volatile uint8_t g_actuator_count  = 2;
volatile uint32_t g_last_event_ms  = 0;

// ============================================================================
// Haptic primitives
// ============================================================================
static void drv_play_effect(uint8_t slot, uint8_t effect_id) {
    if (!g_drv_present || effect_id == 0) return;
    g_drv.setWaveform(slot, effect_id);
}

static void drv_terminate(uint8_t slot) {
    if (!g_drv_present) return;
    g_drv.setWaveform(slot, 0);  // 0 = end-of-sequence marker
}

static void drv_go() {
    if (!g_drv_present) return;
    g_drv.go();
}

// Scale intensity (0..255) onto the DRV2605 overdrive register so quiet
// classifier outputs still feel like a gentle tap and never below threshold.
static void drv_set_intensity(uint8_t intensity) {
    if (!g_drv_present) return;
    uint8_t capped = (intensity > g_intensity_cap) ? g_intensity_cap : intensity;
    g_drv.setRealtimeValue(capped);  // also useful for RTP mode tests
}
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

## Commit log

2026-05-27 feat: OpenHear v1.1.0 — initial public commit
    [BOM.csv, BOM_v2.csv, openhear_v1.5_no_solder.kicad_pcb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]
2026-06-02 fix: get CI green (lint + Noahlink VID/PID test alignment) (#61)
    * fix: get CI green — lint + Noahlink VID/PID test/doc alignment
    The only commit's CI was red on two counts:
    - Lint (ruff): W292 missing trailing newline in
    hardware/sovereign_device/pipeline.py and F541 placeholder-less
    f-string in noahlink_check.py. Both auto-fixed.
    - Tests: test_core_phase4::test_enumerate_devices_filters fed
    enumerate_devices() the stale 0x0484/0x006E ID, but the canonical
    Noahlink dongle ID in core/noahlink.py and the working
    noahlink_check.py libusb-open path is 0x16F0/0x0003. Aligned the
    test and the PROTOCOL_NOTES hint to the real hardware ID; code
    constants were already correct and ar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
2026-06-02 feat(wristband): shared reference codec + contract test for 3-byte haptic packet (#65)
    Closes #64.
    The wristband's BLE command — [sound_class_id, intensity, pattern_id] —
    was defined inline in stream/ble_haptic.py with no decoder and no test,
    while the v1/v2 firmware decoded it positionally on separate silicon.
    Nothing pinned the wire format, so the implementations could drift apart
    silently.
    Adds stream/haptic_packet.py as the dependency-free single source of
    truth: encode_packet/decode_packet, a HapticPacket dataclass
    (to_bytes/from_bytes/to_tuple), and the PACKET_FIELDS / FIELD_INDEX
    layout. stream/ble_haptic.py now re-exports these, so every existing
    import keeps working unchanged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
2026-06-02 feat(wristband): sound->haptic decision policy (priority + confidence + debounce) (#67)
    Adds stream/haptic_policy.py — the missing brain between the classifier
    and the wrist. The classifier emits a ClassifiedSound and the mapper turns
    a class into packet fields, but nothing decided whether a detection should
    fire at all, how urgently, or how to stop it spamming. That gap is what
    makes assistive haptics fail: false buzzes and bursts cause alert fatigue
    and people stop wearing the device.
    HapticPolicy.decide(classified, now_ms) applies three ordered rules:
    1. actionability — silence and non-mapped classes never fire,
    2. confidence gate — detections below a floor are held back,
    3.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
2026-06-02 feat(therapy): Pillar 5 — audiogram-aware binaural beats + protocol model (#69)
    First code for the therapeutic-delivery pillar. Two parts:
    therapy/protocol.py — the evidence-graded, safety-gated TherapeuticProtocol
    data model from the architecture doc: EvidenceGrade (anecdotal..established),
    explicit contraindication gates (seizure disorders barred on every bundled
    protocol via gate()), and a conservatively-graded registry of brainwave
    protocols. Honesty about evidence is enforced by the type, not a footnote.
    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
2026-06-02 feat(therapy): cross-modal haptic entrainment scheduler (#70)
    Adds therapy/entrainment.py — delivery-agnostic rhythmic entrainment. A
    binaural beat needs two audible ear-tones, but the *rhythm* itself doesn't
    care how it reaches you. This renders an entrainment frequency as a precise
    isochronic pulse train and emits it as timestamped 3-byte wristband packets
    (via the shared stream.haptic_packet codec), so a 10 Hz rhythm can be FELT
    on the wrist when it can't be heard — the answer for profound loss where no
    acoustic carrier works.
    The same TherapeuticProtocol can now be delivered acoustically (binaural)
    or haptically (this) or both; the user picks the channel their body can
    receive. even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
2026-06-02 feat(therapy): closed-loop n-of-1 personalisation of entrainment (#72)
    Adds therapy/adapt.py — the honest version of 'an AI tunes the beats'. Not
    an opaque model generating tones, but a deterministic, bounded, explainable
    controller that learns which entrainment frequency and session length work
    for ONE person from their own ratings.
    Mirrors learn/ philosophy: after each session the user leaves a rating
    (-1..+1); record_outcome() appends it as JSONL. personalise(protocol,
    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
2026-06-07 feat(stream): parametrised haptic primitives + continuous crowd-arousal estimation (#80)
    Implements the two foundational layers of the Expanded Sensory Vocabulary v2
    north-star, enabling continuous-channel haptic rendering beyond the v1
    seven-class taxonomy.
    stream/haptic_primitive.py — HapticPrimitive with four composable axes:
    - pulse_rate_hz (0.1–30 Hz): slow throb to rapid buzz
    - intensity (0–255): drive strength, matches existing packet byte
    - spatial_balance (−1.0 left → +1.0 right): directional cue;
    today routes left/centre/right motor; same axis carries angle-of-arrival
    in the multi-actuator v2 hardware path
    - sharpness (0.0–1.0): soft envelope to sharp c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
2026-06-07 feat(stream): performer's beat channel — TempoChannel driving HapticPrimitive at live BPM (#81)
    * feat(stream): add performer's beat channel — TempoChannel driving HapticPrimitive at live BPM
    * refactor(stream): assert beats_per_bar invariant instead of type:ignore (code-review nit)
    ---------
2026-06-10 Scaffold S1 (ContactProfile) + S3 (fatigue-aware DSP) per SUPERIOR_HEARING_ROADMAP v0.2 (#83)
    * Phase 0: ProfileDelta helper + schema extensions for contact_profiles & fatigue
    * Phase 1: ContactProfile bank, CLI, pipeline plumbing (S1 → M2)
    * Phase 2: fatigue-aware DSP hooks (S3 → M6) — local Whoop adapter, bounded bias, CLI
    * Phase 3: mark S1/S3 scaffolded in roadmap; full test suite (1333 passed)
    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
2026-06-15 Add activity telemetry to the output-safety limiter (#84)
    * Add always-on software output-safety limiter to DSP chain
    * Optimise limiter hot path per code review (avoid float64 temp, drop redundant cast)
    * Document always-on output-safety limiter in CHANGELOG
    * Surface output-safety limiter activity telemetry in pipeline + docs
    * Harden limiter telemetry per review (avoid non-finite reduction, stronger summary test)
    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
2026-07-08 chore(release): v1.4.0 — sensory vocabulary v2 + superior hearing scaffold (#86)
    Bundles seven PRs merged since v1.3.0 (2026-06-02):
    #74 therapy: hearing_aids delivery mode for binaural prescription
    (equal gains to avoid double-compensation through fitted aids)
    #79 docs: REGEN_VISION, logging spec, and short-term backlog
    #80 stream: parametrised haptic primitives (HapticPrimitive) +
    continuous crowd-arousal estimation (CrowdArousalEstimator)
    #81 stream: performer's beat channel — TempoChannel driving
    HapticPrimitive at live BPM with bar-accent and EMA smoothing
    #82 docs: SUPERIOR_HEARING_ROADMAP.md — phased path to functionally
    superior heari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
2026-08-05 docs: update README with current industry & institutional engagement (August 2026) (#89)
2026-08-05 docs: README — hero image, remove emoji, TOC, clean opening, fix pillar count (#92)
    * docs: add OpenHear hero image to top of README
    * docs: improve README — remove emoji, clean opening, add TOC, fix pillar count
    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
2026-08-05 Add profile-owned adaptive sensory mapping (#93)
    * Implement adaptive sensory mapping
    * Refine adaptive mapping safeguards
    * Harden adaptive sensory learning
    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
2026-08-05 Add local Iris Sensory Guardian oversight for adaptive haptics (#94)
    * Add Iris sensory guardian oversight
    * Format Iris sensory guardian
    * Ensure unique Iris proposal identifiers
    * Clarify Iris clipped adjustment handling
    * Test Iris oversight loop
    * Clarify Iris no-op test context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
2026-08-12 Living Hearing Profile v5 — first real commitment: advanced multi-layer profile informed by RNID Research Panel day (2026-08-12)
    - Expanded context map with clinical/ICU environments and social noise (direct insight from participants)
    - Refined mid-frequency preference offsets for speech intelligibility under high-frequency sloping loss
    - Strengthened haptic prioritisation for alarms, doorbells and infant cry
    - Replaced all placeholder history hashes with the first authentic Burgess-Principle commitment
    - Profile is no longer a static 2021 audiogram; it is now a living, versioned, user-owned sensory record
2026-08-13 Add opt-in autism and sensory-processing access profiles (#95)
    * Add sensory access profiles
    * Fix sensory profile tests
    * Clarify sensory profile prompts
    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
2026-08-13 Add anonymised profound asymmetric audiogram (Kathryn Richardson, 2022, consented)
    Public example of total nerve deafness left + residual right. Shared with explicit permission for use in Living Hearing Profile materials and documentation. Demonstrates how OpenHear handles profound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
2026-08-15 Harden live wristband accessibility profiles (#96)
    * Wire access profiles into wristband
    * Enforce accessibility haptic ramps
    * Address accessibility runtime review
    * Finalize accessibility haptic safety
    * Polish accessibility control timing
    ---------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
2026-08-15 Align CI tests with haptic policy and profile data (#97)
    * Add safe Iris self-assessment foundation
    * Document Iris self-assessment safeguards
    * Tighten self-assessment threshold safety
    * Bound self-assessment presentations
    * Avoid floor-level self-assessment tones
    * Require bracketed self-assessment thresholds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
2026-08-16 Living Hearing Profile v6 — incorporate lived-experience signals on familiar voices, implant-cusp gap, and listening effort
    - Added familiar_speaker context (known voices vs novel accents / conversational shifts)
    - Strengthened noisy_environment and phone_call notes with speech-in-noise and context-switch difficulty
    - Preference notes updated for listening effort / switching-off pattern
    - New history entry capturing the clinical rationale emerging from RNID panel feedback (cusp-of-implant functional gap, familiar vs unfamiliar talkers)
2026-08-19 Add Auracast design relationship — clean broadcast feed as complementary input to Living Hearing Profile and haptics
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2026-08-23 Add consented anonymised audiogram — moderate-severe bilateral with severe speech-in-noise loss (QuickSIN)
    Public reference example: age-related bilateral moderate-to-severe sloping sensorineural loss with documented severe SNR loss despite moderate PTA. Explicit consent 23 Aug 2026. Complements existing profound-asymmetric and high-frequency-sloping reference profiles.
2026-08-25 CHANGELOG: Living Hearing Profile v9 — SSD spatial, processing lag, tinnitus, aid-out recovery
2026-08-25 feat(therapy): add DermalProfile and 30-100 Hz haptic exploration profiles (Pillar 5) (#98)
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2026-10-17 docs: one canonical intended-purpose statement
    Locks the research claim (environmental sound awareness via haptics, not a certified medical device) so MHRA classification and pilot endpoints have a single source of truth.
2026-10-17 docs: index the canonical intended purpose for regulators
    A regulator or auditor now lands on the single claim file first.
2026-11-09 Align README with intended purpose: awareness only, not a hearing system or aid replacement
    - Soften opening paragraphs to match docs/INTENDED_PURPOSE.md
    - Remove "wristband IS the hearing system" and "aids-free" as current claims
    - Fix licence badge to plain Apache 2.0 (matches LICENSE file)
    - Note that vision sections are exploratory, not the present claim
    - Keeps experimental / not a medical device warning
2026-11-09 Add classifier bench on ESC-50, label snapshot test, and fix firmware pattern-table test
    - scripts/bench_awareness.py: hit rate (Wilson 95% CI) and false alerts for the
    shipped classifier on ESC-50, with a threshold sweep and a signed JSON report.
    Uses YamnetClassifier.classify_window, the call the wristband runtime makes.
    - .github/workflows/bench-awareness.yml: downloads model and dataset at run time.
    - Label map: only 'Knock' fires knock (a door moving is not a knock); DTMF
    dialling no longer fires phone. Full label table pinned by a snapshot test.
    - classify_window accepts min_confidence; loader also accepts ai-edge-litert.
    - Firmware pattern-table test now checks against SOUND_PRO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
2026-11-09 bench workflow: print the signed JSON report in the run log
    Claude-Session: https://claude.ai/code/session_01WDGVSpb5qPNqHQLtwwcn5q
2026-11-10 v1.8.0 work: traffic allowlist, raw scores, two-scheme bench, FSD50K and SONYC-UST loaders
    - stream/sound_classifier.py: traffic is an allowlist of YAMNet indices (302, 306,
    307, 312, 313, 325). Engine, car, truck, bus, motorcycle, road-noise, race-car,
    ice-cream-van, railroad-car and aircraft-engine labels no longer fire it.
    Emergency vehicle (316) joins the sirens under alarm. Adds class_scores(),
    YamnetClassifier.score_window() and classify_window_detailed().
    - scripts/bench_awareness.py (schema 2): stores raw scores for every window and
    class, scores the v1.7.0 and v1.8.0 label maps on identical model output, adds
    per-class precision/recall, the YAMNet label behind each false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
2026-11-10 v1.8.0: publish bench results for ESC-50, FSD50K and SONYC-UST; changelog and version
    docs/BENCH_RESULTS.md is generated from three signed reports committed under
    docs/bench/. Traffic false alerts on engine-only street recordings fall from
    79/374 to 0/374. Horn detection is weak and fell: 22/40 on ESC-50 (was 32/40),
    32/56 on FSD50K, 28/157 on SONYC-UST street recordings. The docs state that the
    traffic pattern is not a safety feature.
    Classifier only, recorded clips, no wearers, not a clinical result.
    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
2026-11-11 docs: bench plan for v1.9.0, committed before any candidate rule is run
    Seven bench-only rules (four voice, two horn... see file), the roles of the
    datasets (ESC-50 chooses; FSD50K and SONYC-UST only confirm) and code-checked
    pass conditions. A rule that costs a siren or alarm hit does not ship.
    This commit contains no results.
    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
2026-11-11 v1.9.0-dev: results for the seven candidate rules; none enabled
    Signed reports for ESC-50, FSD50K and SONYC-UST and the code-computed verdict
    are under docs/bench/. Both horn rules failed (no horn clip recovered on any
    dataset). All four voice rules passed the plan's conditions and stay switched
    off: each trades false alerts for missed speech, and that decision is the
    project owner's. docs/BENCH_RESULTS.md gains the before/after tables, the horn
    breakdown and credits. The shipped classifier is unchanged.
    Classifier only, recorded clips, no wearers, not a clinical result, not
    independently reviewed.
    Claude-Session: https://claude.ai/c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
2026-11-11 Input probes: results for ESC-50, FSD50K and SONYC-UST (measurement only)
    Neither shifted windows nor band-limited resampling fixes horn detection.
    Band-limited resampling did not meet the plan's condition and is not proposed:
    no horn gain and 42 more false-alert clips on FSD50K; 2 more horn clips and 5
    more false-alert clips on SONYC-UST. On SONYC-UST 51 of 185 horn clips fire
    under shipped or shifted windows against 36 as shipped. The shipped classifier
    is unchanged.
    Claude-Session: https://claude.ai/code/session_01WDGVSpb5qPNqHQLtwwcn5q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

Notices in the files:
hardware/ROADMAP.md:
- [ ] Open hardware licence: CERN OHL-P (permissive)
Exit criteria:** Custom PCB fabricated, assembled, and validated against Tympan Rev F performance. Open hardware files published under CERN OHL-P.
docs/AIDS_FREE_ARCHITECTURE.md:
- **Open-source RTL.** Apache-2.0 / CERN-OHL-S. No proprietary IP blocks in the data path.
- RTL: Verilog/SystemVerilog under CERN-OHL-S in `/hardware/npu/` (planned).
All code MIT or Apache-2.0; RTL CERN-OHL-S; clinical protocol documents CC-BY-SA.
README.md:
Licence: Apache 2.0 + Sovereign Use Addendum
